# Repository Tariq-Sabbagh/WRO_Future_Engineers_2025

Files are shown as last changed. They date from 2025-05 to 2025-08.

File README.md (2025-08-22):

<center><h1>ITE  - Bloody Hilux WRO 2025 </center>

<p align="center">
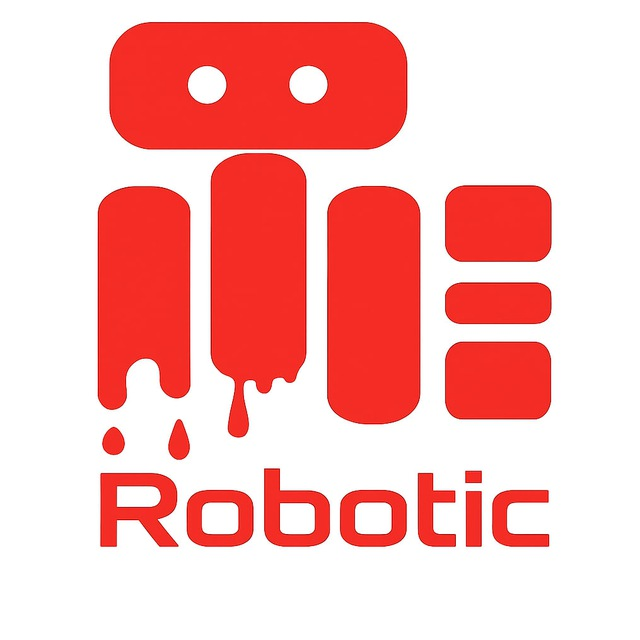
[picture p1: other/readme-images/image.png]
Banner
  
</p>





## Table of Contents

* [The Team](#team)
* [The Challenge](#challenge)
* [The Robot](#robot-image)
* [Performance Video](#video)
* [Mobility Management](#mobility-management)
  * [Powertrain](#powertrain-mechanical)
    * [Drive Motor](#motor-mechanical)
    * [Motor Driver](#motor-driver-mechanical)
  * [Steering](#steering-mechanical)
    * [Servo Motor](#servo-motor)
  * [Chassis](#chassis-mechanical)
* [Power and Sense Management](#power-and-sense-management)
  * [PCB Design](#pcb)
  * [Main Processor](#main-processor)
  * [Microcontroller](#microcontroller)
  * [Li-Po Battery](#li-ion-battery)
  * [Power Regulation](#power-regulation)
  * [Sensors](#sensors)
* [Code and Algorithms](#code-and-algorithms)
  * [Vision Processing and Obstacle Detection (Python)](#obstacle-management)
  * [Real-Time Control and State Machine (C++)](#real-time-control)
* [License](#copyright)

---

## The Team 

### [Team Member 1 Tariq Al-Sabbagh Al-Taji]

<p align="center">
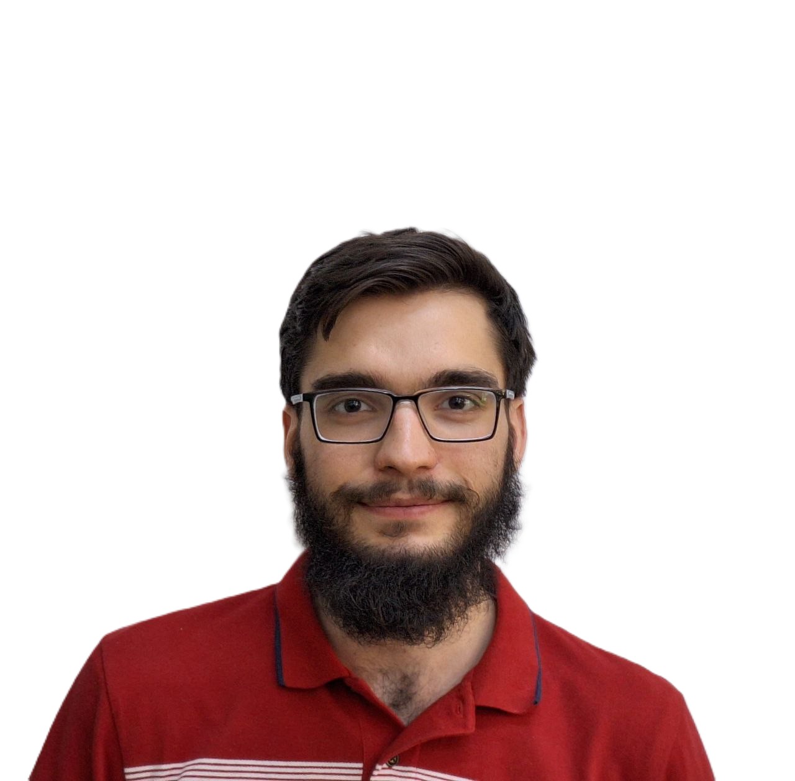
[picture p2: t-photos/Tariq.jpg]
Tariq sabbagh
  
</p>

<b>Role:</b> Programmer

<b>Age:</b> 21

<b>University:</b> Damascus University

<b>Description:</b>  A third-year Information Technology Engineering student at Damascus University. He is a backend developer and a volunteer at the Robotics Club.

---

### [Team Member 2 Tayseer Matar]

<p align="center">
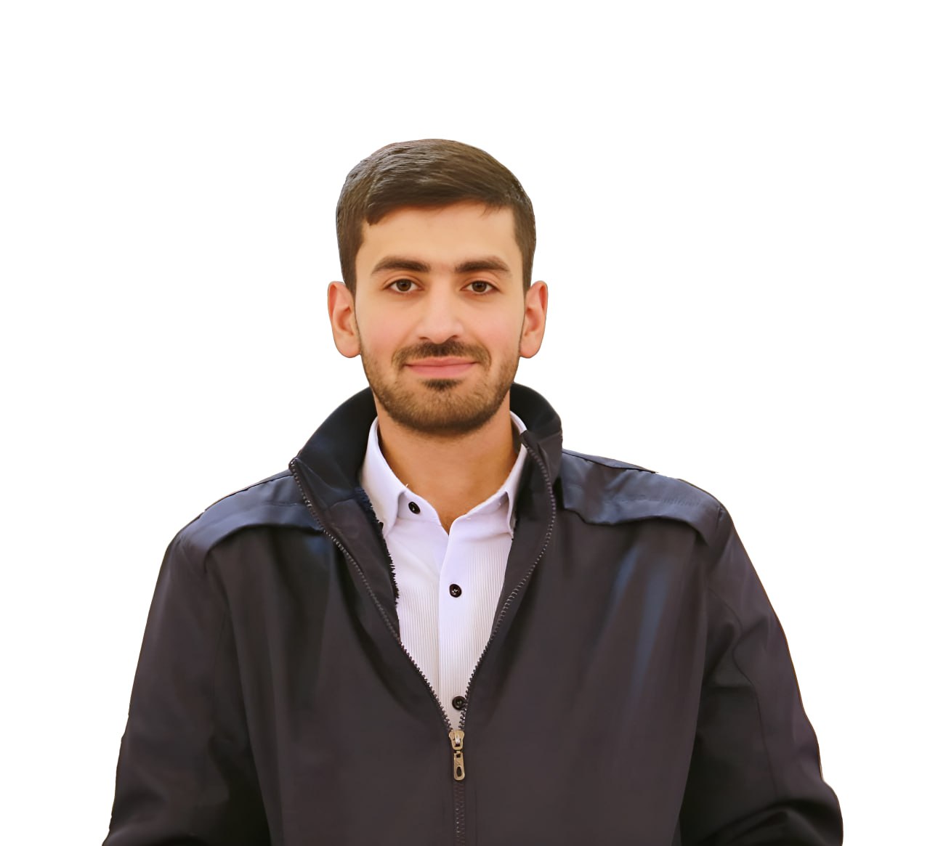
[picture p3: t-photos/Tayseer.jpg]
Tayseer matar
  
</p>

<b>Role:</b> Electrical

<b>Age:</b> 21

<b>University:</b> Damascus University

<b>Description:</b> A third-year Information Technology Engineering student at Damascus University. He is a frontend developer and a volunteer at the Robotics Club.

---

### [Team Member 3 Abdulrahman Qassouma]

<p align="center">
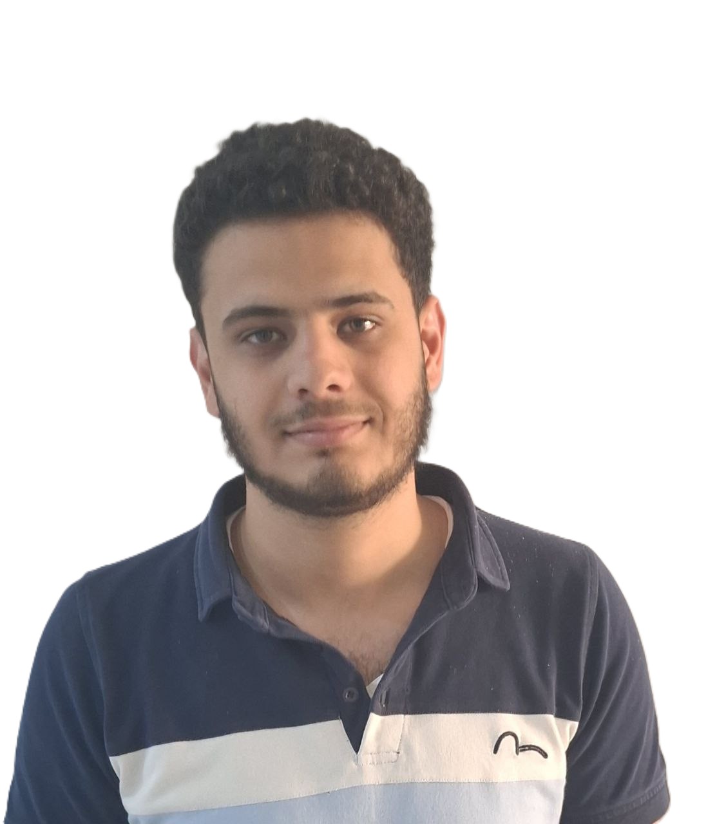
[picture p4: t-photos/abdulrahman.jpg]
Abdulrahman qassouma
  
</p>

<b>Role:</b> 3D design and the development of mechanical systems

<b>Age:</b> 21

<b>University:</b> Damascus University

<b>Description:</b>  A second-year Mechanical Design Engineering student at Damascus University. He specializes in 3D design and the development of mechanical systems.

---

### [Mohammed Mouaaz Sweid]

<p align="center">
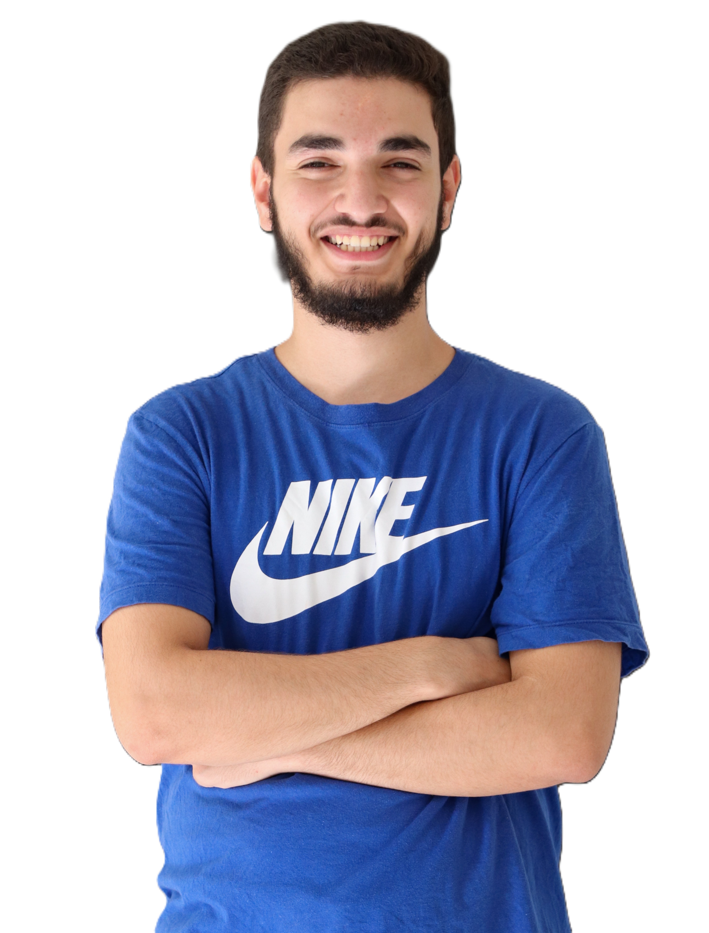
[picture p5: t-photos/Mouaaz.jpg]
Mohammed Moaz Sweid
  
</p>

<b>Role:</b> Coach

<b>Description:</b> A third-year Information Technology  Engineering student at Damascus University. He is a backend and DevOps developer and serves as a coach at the university's Robotics Club.

---

### Team Photo

<p align="center">
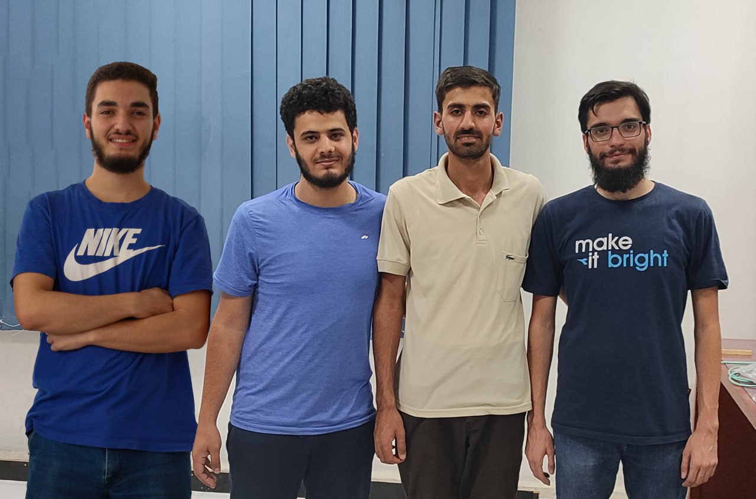
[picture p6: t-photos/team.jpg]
team Photo
  
</p>

## The Challenge 

The **[WRO 2025 Future Engineers - Self-Driving Cars](https://wro-association.org/)** challenge invites teams to design, build, and program a robotic vehicle capable of driving autonomously on a racetrack that changes dynamically for each round. The competition includes two main tasks: completing laps while navigating randomized obstacles and successfully performing a precise parallel parking maneuver.

---

## Photos of our robot Bloody Hilux 

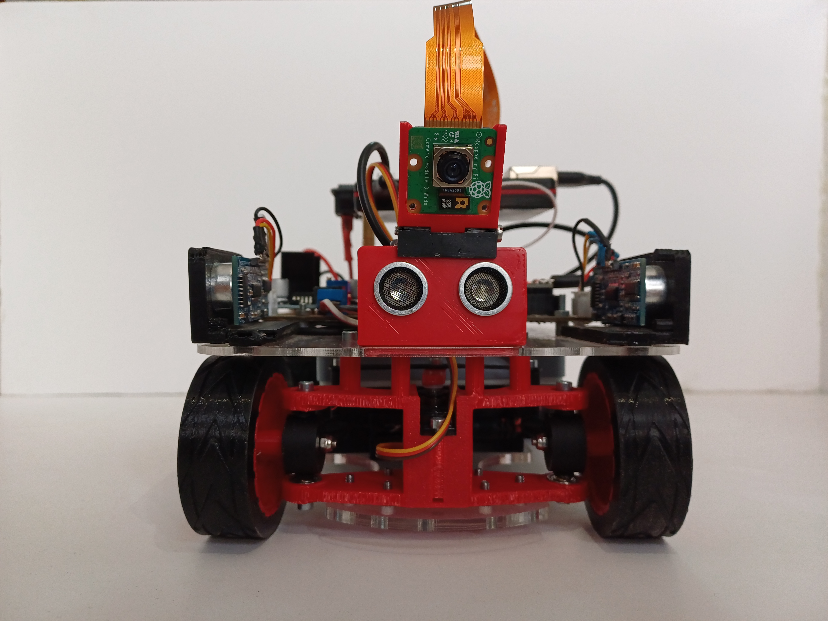
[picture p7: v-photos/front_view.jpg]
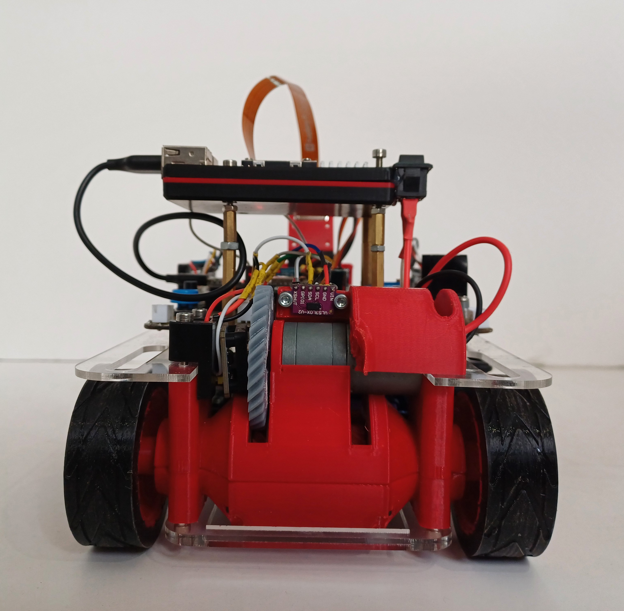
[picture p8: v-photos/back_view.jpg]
 |  | 

| *Front* | *Back* |

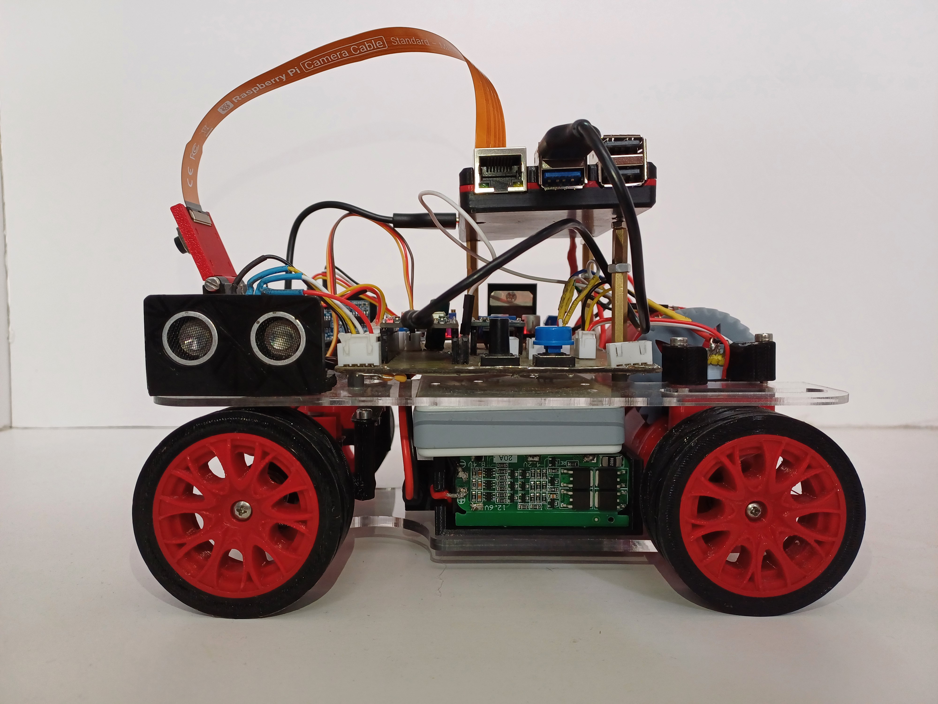
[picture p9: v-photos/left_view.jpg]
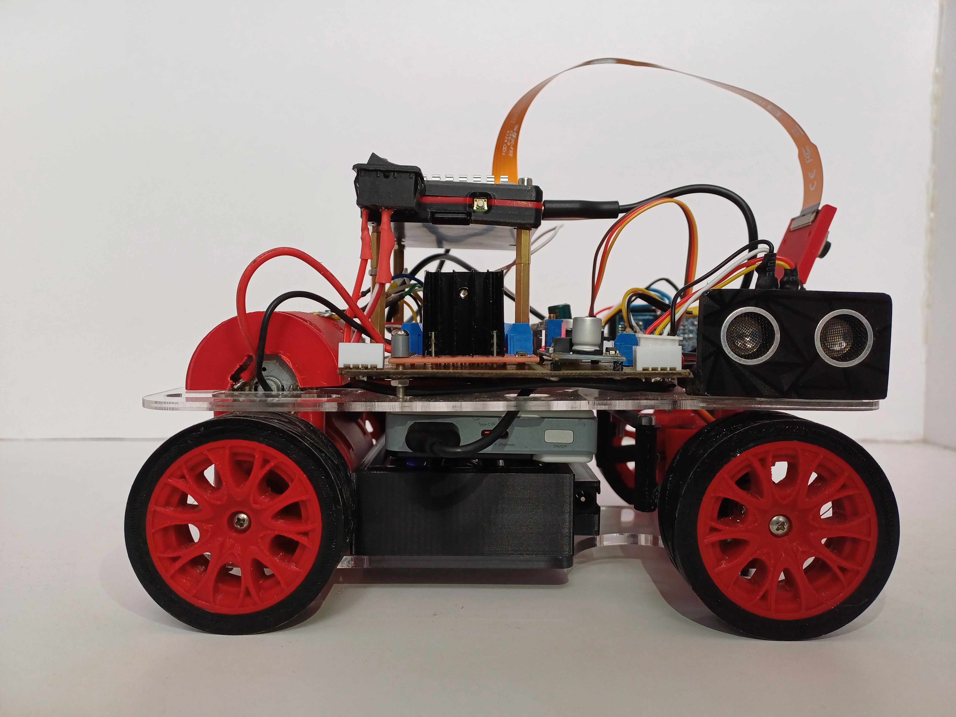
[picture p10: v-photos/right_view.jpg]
 |  | 

| *Left* | *Right* |

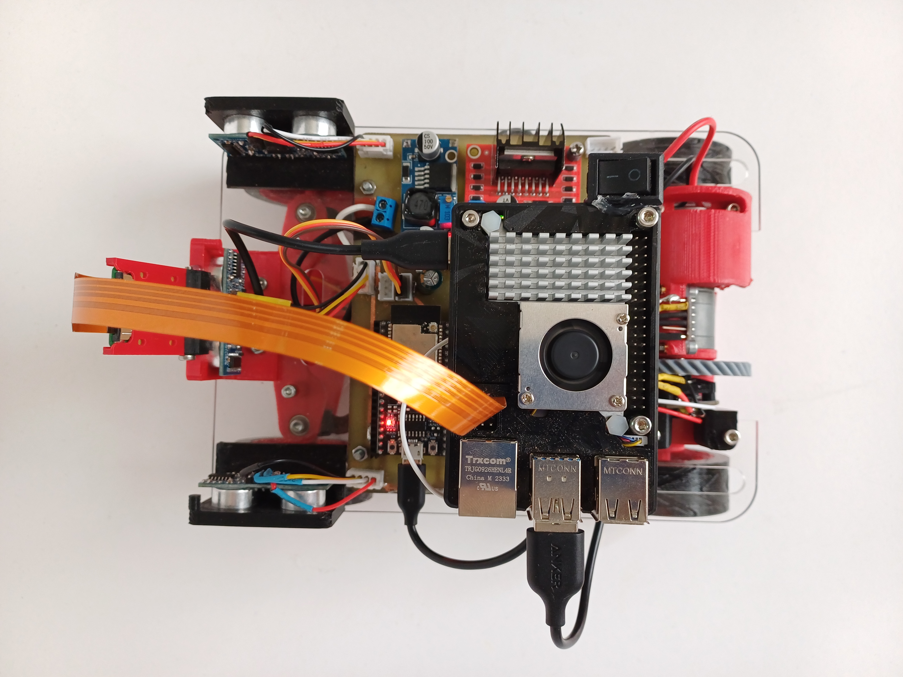
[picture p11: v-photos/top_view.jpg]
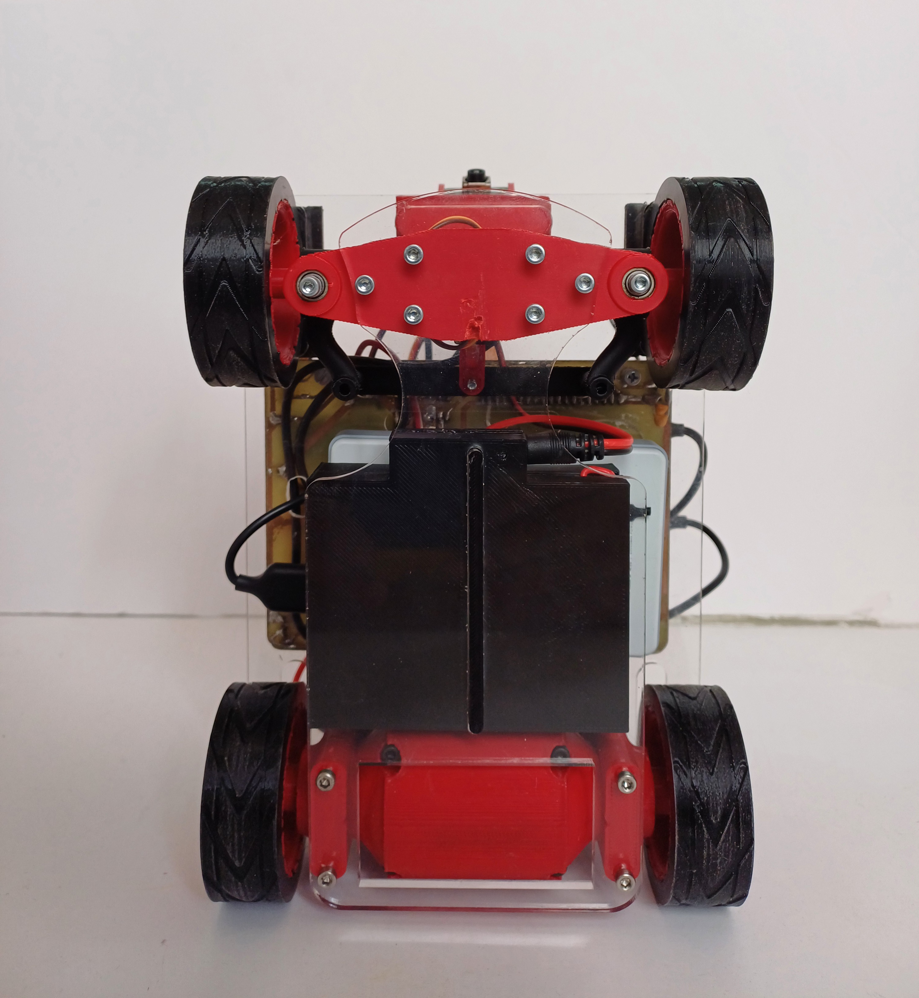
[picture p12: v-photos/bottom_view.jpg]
 |  | 

| *Top* | *Bottom* |

<br>

## Our video of the robot on [Youtube](https://youtu.be/ZicO00x3EqA?feature=shared) 

<a href="https://youtu.be/ZicO00x3EqA?feature=shared" target="_blank">
 <p align="center">
  WRO 2025 Robot Performance Video
 </p>
</a>

<br>

# [Mobility Management](https://github.com/Tariq-Sabbagh/WRO_Future_Engineers_2025/blob/main/models/README.md) 
Our robot's mechanical design is engineered for a precise balance of speed, stability, and cornering efficiency. The core components—powertrain, steering, and chassis—work together to achieve reliable and consistent performance on the track.

## Powertrain 

### Drive Motor 

<table>
  <tr>
    <td width="50%" style="text-align: left;">
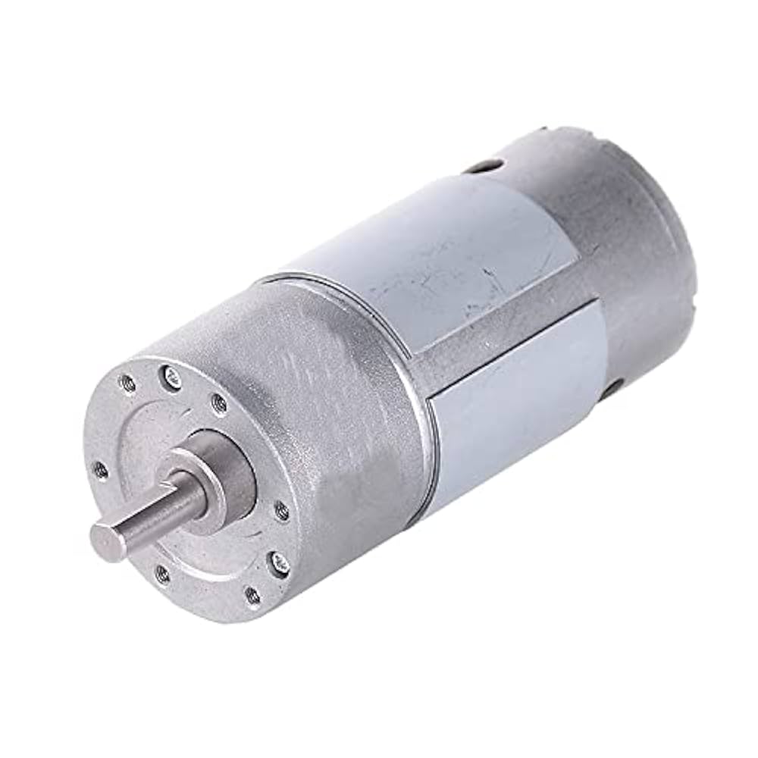
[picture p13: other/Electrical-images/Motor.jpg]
DC Motor
  
</td>
    <td width="50%" style="text-align: left; vertical-align: top;">
      <h3>Specifications:</h3>
      <li>Voltage: 12 V</li>
      <li>Speed: 281 RPM</li>
      <li>Torque: 5 kgf·cm (~0.49 N·m)</li>
    </td>
  </tr>
</table>

**Description:** This DC motor was selected because it provides the best trade-off between torque and speed. It ensures strong acceleration and a reliable top speed on straight tracks. The motor is paired with a 2.2:1 gear ratio to increase wheel speed, a suitable trade-off for the flat competition track.

### Motor Driver 
<table>
  <tr>
    <td width="50%" style="text-align: left;">
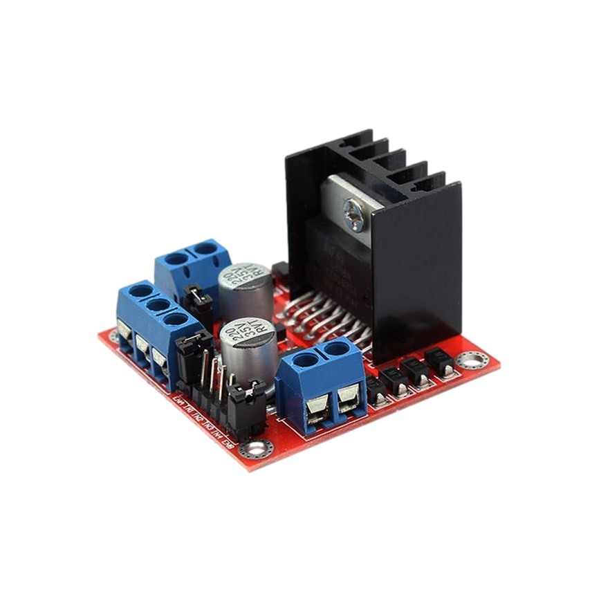
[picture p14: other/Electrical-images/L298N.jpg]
  
</td>
    <td width="50%" style="text-align: left; vertical-align: top;">
      <h3>Specifications:</h3>
      <li>Power supply voltage: 12V</li>
      <li>Output current: Up to 2A per channel</li>
      <li>Control: PWM for speed, Digital pins for direction</li>
    </td>
  </tr>
</table>

**Description:** We are using the L298N motor driver to safely interface the ESP32 with the high-current DC motor. It allows us to control both the speed (via PWM) and the direction of the motor. It is powered directly from the 12V battery pack.

## Steering 

**Description:** Our steering system is custom-designed based on Ackermann geometry. This ensures that the inner and outer wheels follow their correct turning radii (inner wheel at 65°, outer at 38°), which minimizes tire drag and makes cornering highly precise and stable. The mechanism is built with custom 3D-printed parts and durable linkages.

### Servo Motor 

<table>
  <tr>
    <td width="50%" style="text-align: left;">
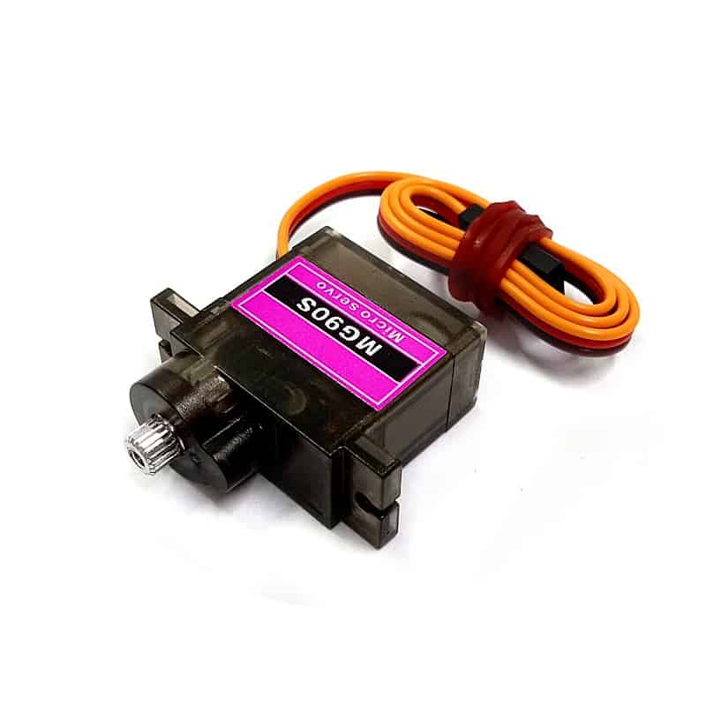
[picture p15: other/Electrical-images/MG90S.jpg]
  
</td>
    <td width="50%" style="text-align: left; vertical-align: top;">
      <h3>Specifications:</h3>
      <li>Weight: 9.3 g</li>
      <li>Rotation angle: 0 - 180</li>
    </td>
  </tr>
</table>

**Description:** A single servo motor actuates our Ackermann steering mechanism. It was chosen for its reliability and sufficient torque to handle the steering linkages under load.

## Chassis 

**Description:** The chassis is a hybrid construction using two plexiglass plates as the main structure, connected by custom 3D-printed support components. This design provides an excellent balance of durability and lightness, with a total weight of approximately 1.25 – 1.3 kg. All components are strategically placed to keep the center of gravity low, which is critical for maintaining stability at high speeds and during sharp turns.

Chassis

---

# # [Power and Sense Management](https://github.com/Tariq-Sabbagh/WRO_Future_Engineers_2025/blob/main/e-schemes/README.md) 
Our robot's electronic system is a two-part brain, with a Raspberry Pi 5 handling high-level vision processing and an ESP32 managing real-time hardware control. This distributed architecture ensures that complex calculations do not interfere with the precise, low-latency actions required for navigation.

### PCB Design 

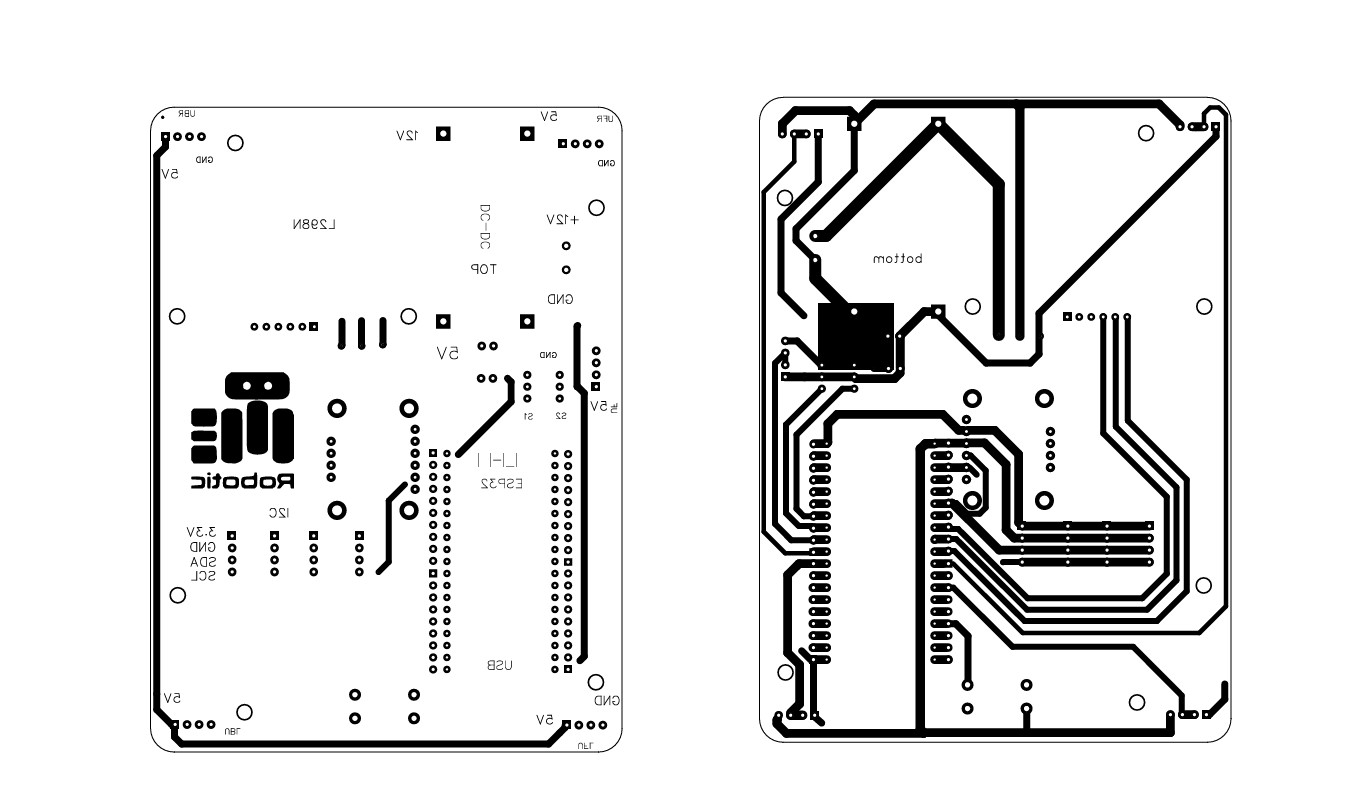
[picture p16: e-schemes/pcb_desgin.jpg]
PCB Design


**Description:** To ensure reliable connections and an organized layout, we integrated all our core electronic components onto a central PCB. This board serves as the main hub for power distribution, taking the 12V input from the battery pack and routing it through the power switch and LM2596 voltage regulator to supply all other components. Using a PCB instead of loose wires significantly improves the robot's durability by preventing accidental disconnections and makes troubleshooting much easier.

### Main Processor 
<table>
  <tr>
   <td width="50%" style="text-align: left;">
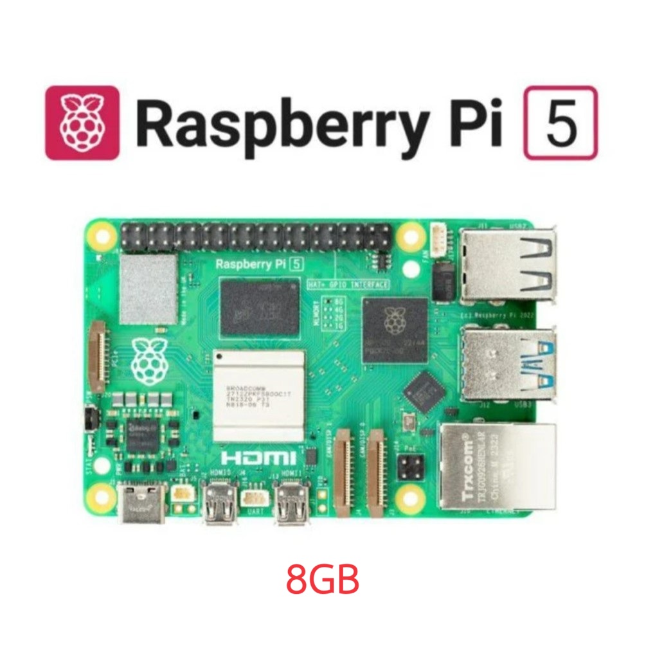
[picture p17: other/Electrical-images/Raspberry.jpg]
  
</td>
    <td width="50%" style="text-align: left; vertical-align: top;">
      <h3>Specifications:</h3>
      <li>Processor: Broadcom BCM2712 2.4GHz quad-core 64-bit Arm Cortex-A76 CPU</li>
      <li>RAM: 8 GB</li>
      <li>Power: 5V/5A DC via USB-C</li>
    </td>
  </tr>
</table>

**Description:** The Raspberry Pi 5 serves as the main brain for all high-level computations. It runs our Python-based computer vision algorithms using OpenCV to process the camera feed, detect obstacles, and identify turn indicators. It then sends high-level commands (e.g., "avoid obstacle at this angle") to the ESP32 via USB serial communication.

### Microcontroller
<table>
  <tr>
    <td width="50%" style="text-align: left;">
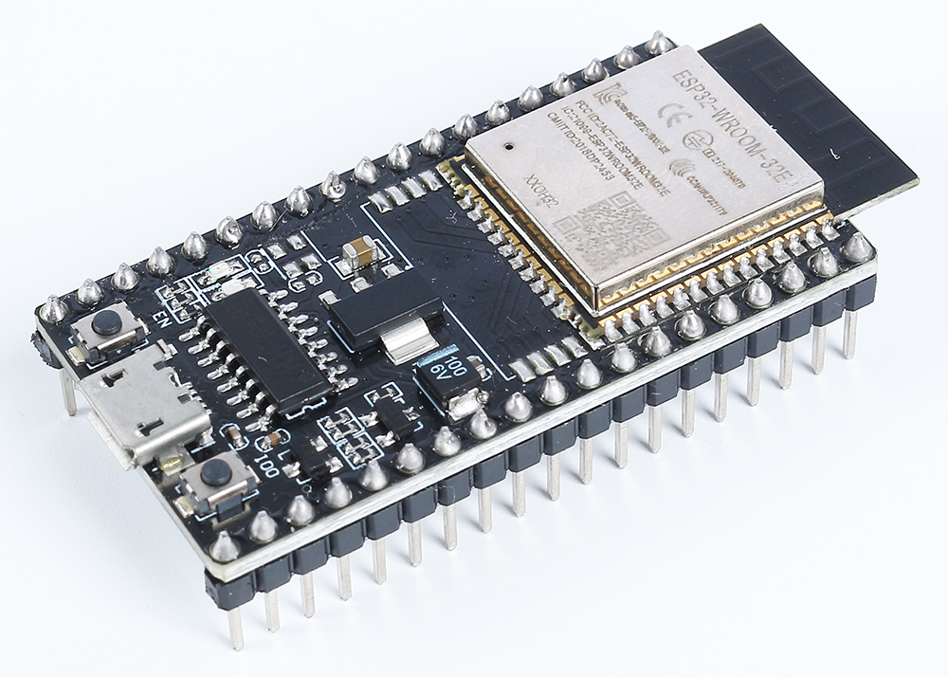
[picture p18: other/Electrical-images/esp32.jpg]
  
</td>
    <td width="50%" style="text-align: left; vertical-align: top;">
      <h3>Specifications:</h3>
      <li>Microcontroller: ESP32</li>
      <li>Frequency: 240 MHz (Dual Core)</li>
      <li>Flash memory: 4 MB</li>
    </td>
  </tr>
</table>

**Description:**We chose the ESP32 for its powerful dual-core processor and reliability in real-time operations. It acts as the hardware controller, executing the commands sent by the Raspberry Pi. Its responsibilities include generating precise PWM signals for the motor and servo, and gathering data from all the low-level sensors (IMU, Encoders, etc.) with minimal latency.

### Li-ion Battery 

<table>
  <tr>
   <td width="50%" style="text-align: left;">
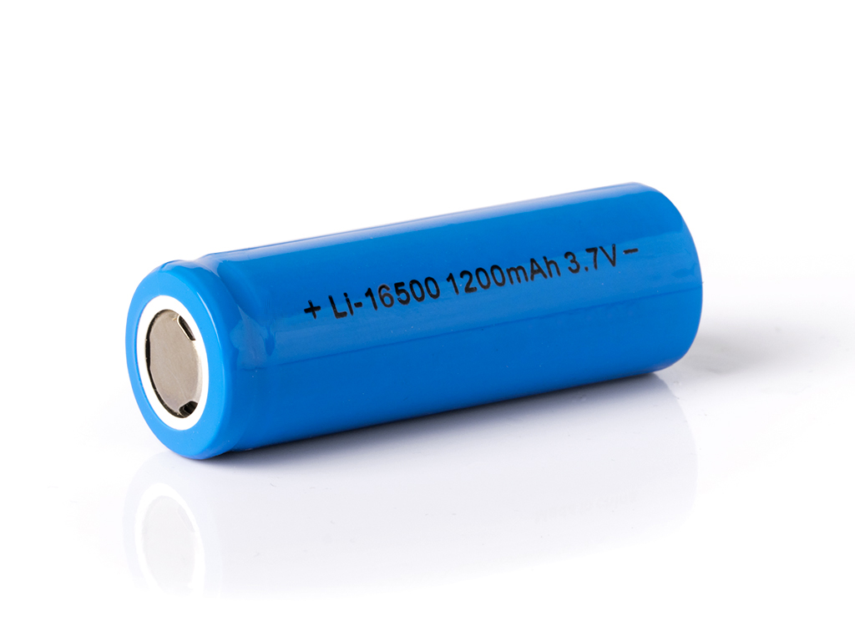
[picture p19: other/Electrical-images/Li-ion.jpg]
  
</td>
    <td width="50%" style="text-align: left; vertical-align: top;">
      <h3>Specifications:</h3>
      <li>Capacity: 5000 mA</li>
      <li>Voltage: 12V (3S Configuration)</li>
      <li>Protection: BMS 3S for overcharge/discharge protection</li>
    </td>
  </tr>
</table>

**Description:**  The main power for the motors and PCB comes from a 12V battery pack, constructed from three 18650 Li-ion cells in series. A BMS 3S board is integrated to ensure safe charging, prevent over-discharge, and provide a stable 12V output. This power is regulated by an LM2596 step-down converter for the electronics

### Power Regulation
<table>
  <tr>
    <td width="50%" style="text-align: left;">
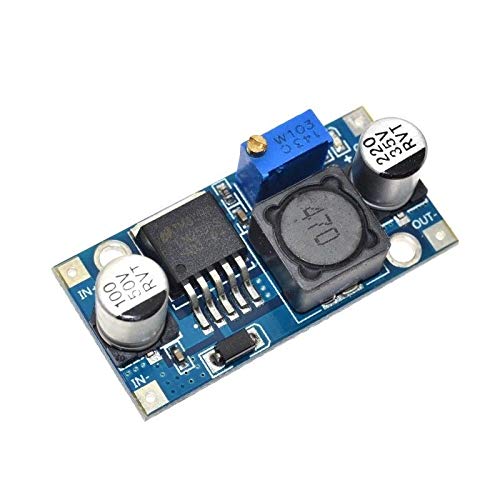
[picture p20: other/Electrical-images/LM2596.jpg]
  
</td>
    <td width="50%" style="text-align: left; vertical-align: top;">
      <h3>Specifications:</h3>
      <li>Input Voltage: 12V</li>
      <li>Output Voltage: 5V / 3.3V (Adjustable)</li>
      <li>Max Current: 3A</li>
    </td>
  </tr>
</table>

**Description:** An LM2596 step-down voltage regulator is used to convert the 12V from the main battery pack into a stable 5V or 3.3V supply for the microcontrollers and sensors. This is crucial for protecting the sensitive electronics from the high voltage of the battery.

### Sensors  

#### Camera
<table>
  <tr>
   <td width="50%" style="text-align: left;">
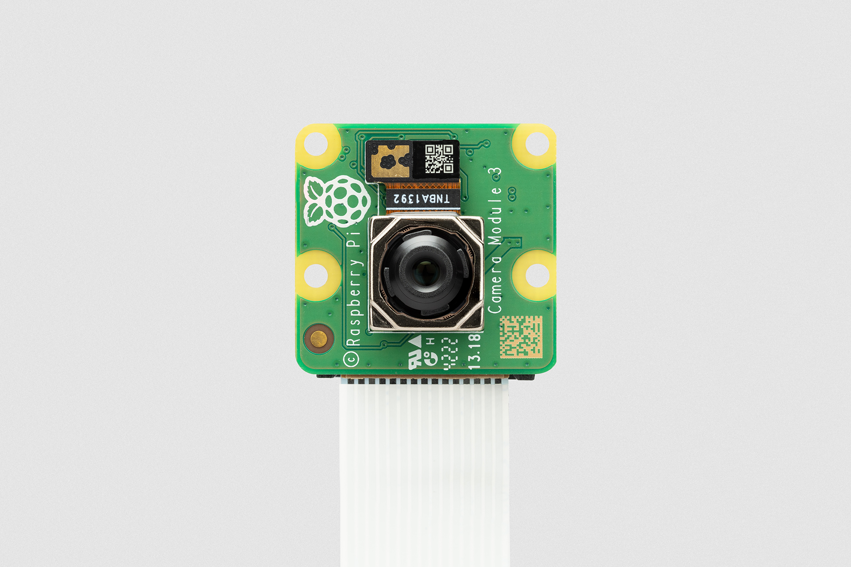
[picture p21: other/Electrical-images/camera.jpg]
  
</td>
    <td width="50%" style="text-align: left; vertical-align: top;">
      <h3>Specifications:</h3>
      <li>Resolution: 12 Megapixels (4056×3040)</li>
      <li>Frame rate: Up to 60 fps</li>
    </td>
  </tr>
</table>

**Description:**  The Raspberry Pi Camera V3 is our primary sensor for vision processing. Connected directly to the Raspberry Pi 5, it provides a high-resolution video stream that is analyzed in real-time to detect colored obstacles and track lines on the course.

#### IMU Sensor

<table>
  <tr>
    <td width="50%" style="text-align: left;">
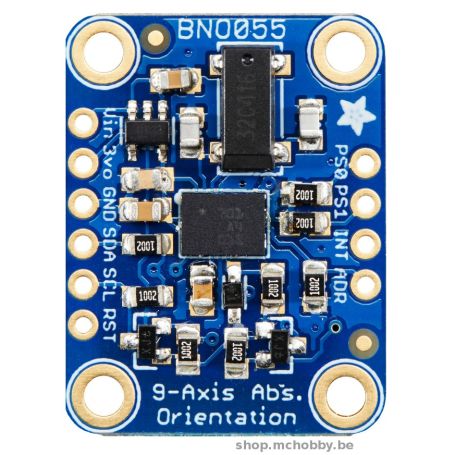
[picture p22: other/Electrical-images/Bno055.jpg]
  
</td>
    <td width="50%" style="text-align: left; vertical-align: top;">
      <h3>Specifications:</h3>
      <li>Gyroscope range: ±2000 dps</li>
      <li>Accelerometer range: ±4g</li>
      <li>Communication: I2C</li>
    </td>
  </tr>
</table>

**Description:** The BNO055 IMU is crucial for navigation and stability. It provides accurate orientation data (heading), which is fed into our PID steering controller. This allows the robot to drive in a perfectly straight line and execute turns with high precision.

#### Ultrasonic Sensors
<table>
  <tr>
  <td width="50%" style="text-align: left;">
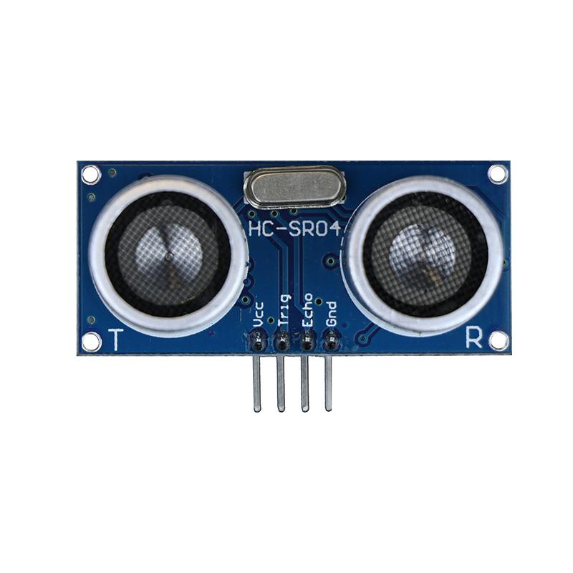
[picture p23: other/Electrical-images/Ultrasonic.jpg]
  
</td>
    <td width="50%" style="text-align: left; vertical-align: top;">
      <h3>Specifications:</h3>
      <li>Range: 2cm - 400cm</li>
      <li>Purpose: Wall and obstacle detection</li>
    </td>
  </tr>
</table>

**Description:** Three ultrasonic sensors (front, left, and right) are used for general distance measurement and obstacle avoidance. They provide reliable data for detecting walls during turns and serve as a secondary system to the camera for avoiding unexpected objects.

#### Time-of-Flight (ToF) Sensor

<table>
  <tr>
   <td width="50%" style="text-align: left;">
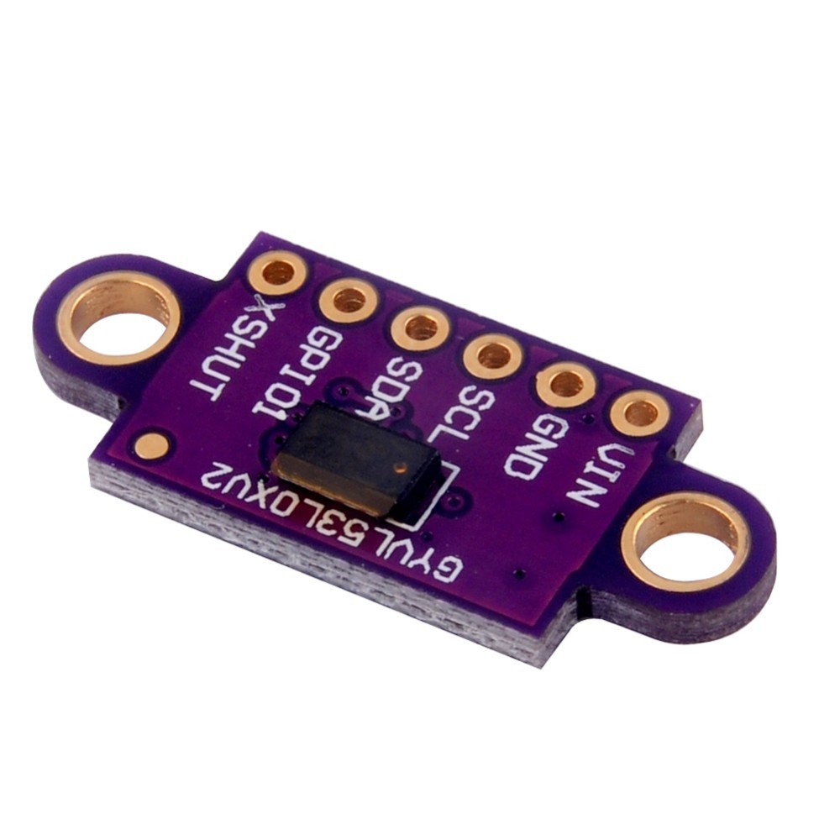
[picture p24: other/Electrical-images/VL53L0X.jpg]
  
</td>
    <td width="50%" style="text-align: left; vertical-align: top;">
      <h3>Specifications:</h3>
      <li>Range: Up to 2m</li>
      <li>Technology: Laser-based</li>
      <li>Communication: I2C</li>
    </td>
  </tr>
</table>

**Description:**  A VL53L0X ToF sensor is mounted on the rear of the robot. It uses a laser to measure distances with high speed and precision. Its primary role is to accurately position the robot against the back wall after a turn, ensuring a consistent starting point for each new section of the track.

#### Magnetic Encoder
<table>
  <tr>
   <td width="50%" style="text-align: left;">
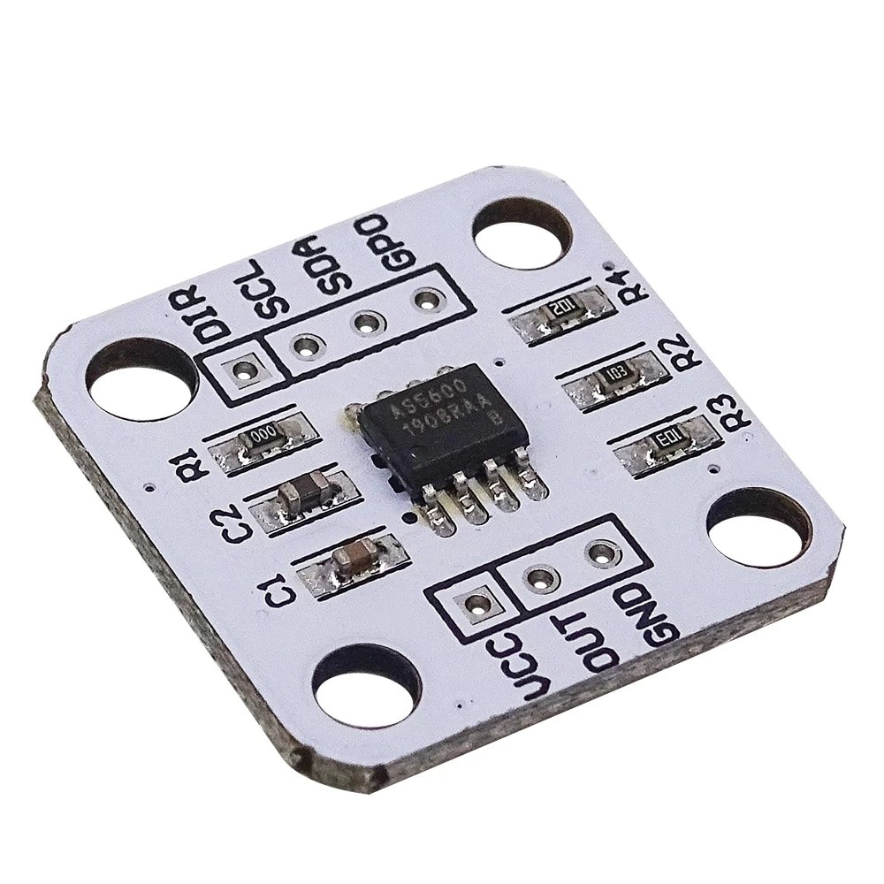
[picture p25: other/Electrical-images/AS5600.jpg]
  
</td>
    <td width="50%" style="text-align: left; vertical-align: top;">
      <h3>Specifications:</h3>
      <li>Resolution: 12-bit (4096 positions per revolution)</li>
      <li>Technology: Hall-effect</li>
      <li>Communication: I2C</li>
    </td>
  </tr>
</table>

**Description:** The AS5600 magnetic encoder is attached to the motor shaft to provide high-precision feedback on wheel rotation. This allows us to accurately track the distance traveled, which is essential for executing precise avoidance maneuvers and for odometry calculations.

# [ Code and Algorithms ](https://github.com/Tariq-Sabbagh/WRO_Future_Engineers_2025/blob/main/src/README.md)

Our robot's intelligence is built on a distributed software architecture. A Python script on the `Raspberry Pi 5` handles all the complex computer vision tasks, acting as the "eyes" of the robot. It communicates high-level commands to a C++ firmware running on the `ESP32`, which serves as the "nervous system," executing physical movements with real-time precision.

# Vision Processing and Obstacle Detection (Python) 

The core of our autonomous navigation is the vision script running on the Raspberry Pi. It processes the camera feed in real-time to identify obstacles and turn indicators.

* **Reliable Color Detection:** To detect objects under varying lighting conditions, we convert images from RGB to the LAB color space. This allows us to isolate specific colors accurately, regardless of shadows or bright spots on the track.

* **Focused Processing (ROI):** To improve performance and reduce false detections, we don't process the entire image. Instead, we define a specific Region of Interest (ROI) in the lower part of the frame where we expect to see the track, focusing our processing power only where it matters.

* **Maneuver Calculation:** When an obstacle is detected, the script calculates a precise avoidance maneuver. It estimates the distance to the obstacle based on its apparent height and the required steering angle based on its horizontal position. These two values are then sent as a single command to the ESP32.

```python
def process_obstacle(self, contour, frame_rgb, color_type):
    # Calculate distance from the obstacle's height
    distance = self.calculate_distance(h)
    # Calculate the angle and path to avoid it
    travel_dist, turn_angle = self.calculate_maneuver(...)

    # Send the command to the robot
    self.send_command('AVOID', travel_dist, turn_angle)
```

# Real-Time Control and State Machine (C++) 
The ESP32 firmware is designed for robust, real-time control. It receives commands from the Raspberry Pi and translates them into precise hardware actions using a clean and predictable structure.

* **State Machine:** The core of the firmware is a state machine. The robot operates in distinct states such as FORWARD, AVOIDING, TURN, and RESET. This approach allows us to manage complex sequences of actions in an organized way, making the robot's behavior reliable and easy to debug.
```cpp
void ObstacleAvoider::loop()
{
    // ... update sensors and check for commands ...

    switch (_currentState)
    {
    case AVOIDING: _avoidObstacle(); break;
    case FORWARD:  _goForward();     break;
    case TURN:     _turn();          break;
    case RESET:    _resetCar();      break;
    }
}
```

* **PID Control for Precision:** To drive perfectly straight and execute smooth turns, we use a PID controller. It continuously takes the current heading from the `BNO055 IMU` and compares it to the target heading, calculating the exact steering correction needed. This feedback loop is the key to our robot s stability and accuracy.

* **Code Structure and Helper Classes:** To keep the main logic clean, our C++ code is heavily object-oriented. We developed a suite of helper classes, where each class is responsible for managing a single piece of hardware (e.g., `MotorController`, `IMU`, `Encoder`, `PIDController`). This abstraction allows us to easily manage complex hardware interactions without cluttering the main state machine.

## Copyright 

```
MIT License

Copyright (c) 2025 Bloody Hilux

Permission is hereby granted, free of charge, to any person obtaining a copy
of this software and associated documentation files (the "Software"), to deal
in the Software without restriction, including without limitation the rights
to use, copy, modify, merge, publish, distribute, sublicense, and/or sell
copies of the Software, and to permit persons to whom the Software is
furnished to do so, subject to the following conditions:

The above copyright notice and this permission notice shall be included in all
copies or substantial portions of the Software.

THE SOFTWARE IS PROVIDED "AS IS", WITHOUT WARRANTY OF ANY KIND, EXPRESS OR
IMPLIED, INCLUDING BUT NOT LIMITED TO THE WARRANTIES OF MERCHANTABILITY,
FITNESS FOR A PARTICULAR PURPOSE AND NONINFRINGEMENT. IN NO EVENT SHALL THE
AUTHORS OR COPYRIGHT HOLDERS BE LIABLE FOR ANY CLAIM, DAMAGES OR OTHER
LIABILITY, WHETHER IN AN ACTION OF CONTRACT, TORT OR OTHERWISE, ARISING FROM,
OUT OF OR IN CONNECTION WITH THE SOFTWARE OR THE USE OR OTHER DEALINGS IN THE
SOFTWARE.

```

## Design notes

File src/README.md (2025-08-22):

# Code Logic and Strategy

## Open Challenge

### Core Logic: The `Car` Class

To keep our code organized and easy to manage, we built our entire driving logic inside a single C++ class called `Car`. This class acts as the "brain" of our robot. It brings together all the different hardware components—motors, steering, sensors—and uses a clear algorithm to navigate the challenge track.

Here is the basic structure of our `Car` class:
```cpp
#include "PIDController.h"
#include "MotorController.h"
#include "Steering.h"
#include "DistanceSensors.h"
#include "IMU.h"
#include "Button.h"

class Car {
private:
    // All our hardware objects
    MotorController _motors;
    Steering _steering;
    DistanceSensors _distSensors;
    IMU _imu;
    Button _button;
    PIDController _pid;

    // Variables to track our state on the track
    float _offsetGyro;
    int _turnCounter;
    // ... and other state variables

    // The core actions the car can take
    void _checkForTurns();
    void _moveStraight();
    void _turnRight();
    void _turnLeft();
    void _stopAndHalt();

public:
    // Public functions to run the car
    Car();
    void setup();
    void loop();
};
```
Constructor: Car()
This is where the Car object is first created. Its main job is to initialize all the hardware component objects (like _motors, _steering, etc.) with their correct pin numbers. It also resets all our navigation variables to their starting values, ensuring a clean start for every run.
```cpp
Car::Car() :
    _motors(MOTOR_DIR1_PIN, MOTOR_DIR2_PIN, MOTOR_SPEED_PIN),
    _steering(SERVO_PIN),
    _distSensors(ULTRASONIC_PIN_FRONT, ULTRASONIC_PIN_LEFT, ULTRASONIC_PIN_RIGHT),
    _imu(),
    _button(BUTTON_PIN),
    _pid()
{
    // Reset state variables
    _offsetGyro = 0.0f;
    _turnCounter = 0;
    direction = "straight";
    // ... etc.
}
```
Setup Phase: setup()
The setup() function gets all the hardware ready to go. It configures our PID controller for smooth steering and initializes the IMU sensor. A key feature here is that the code waits for a button press. This allows us to place the robot on the track before it starts moving. Once the button is pressed, it calibrates the gyro by taking an initial reading to know its starting direction.
```cpp
void Car::setup() {
    // Setup all hardware components
    _motors.setup();
    _steering.setup();
    _button.setup();
    
    // Configure PID controller
    _pid.setup(STEERING_KP, 0, 0);
    _pid.setOutputLimits(-90,90);
    
    // Initialize IMU, and stop if it fails
    if (!_imu.setup()) {
        _stopAndHalt();
    }

    // Wait for the start signal
    _button.waitForPress();
    
    // Calibrate gyro to the starting direction
    _imu.update();
    _offsetGyro = _imu.getHeading();
}
```
Main Loop: loop()
This is the heart of our program that runs over and over. The logic is very simple and clear:

Update Sensors: Always get the latest data from the IMU first.

Check for Turns: See if the robot has reached an intersection where it needs to turn.

Drive Straight: Use the PID controller to maintain a perfectly straight line.

Check Finish Condition: After 12 turns, the robot knows the course is complete and stops.

```cpp
void Car::loop() {
    _imu.update(); // 1. Update Sensors
    
    _checkForTurns();   // 2. Check for Turns
    _moveStraight();    // 3. Drive Straight

    // 4. Check if we're done
    if (_turnCounter >= 12) {
        // ... stop the car
        _stopAndHalt();
    }
}
```

Core Functions Explained
_moveStraight()
This function is responsible for keeping the car on course. It constantly compares the car current heading (from the IMU gyro) to its target direction. The difference between these is the "error." This error is fed into a PID controller, which calculates the precise steering correction needed to get back on track. This allows the robot to drive very straight.

```cpp
void Car::_moveStraight() {
    // Calculate heading error relative to our starting direction
    float currentHeading = _imu.getHeading() - _offsetGyro;

    // Normalize the heading to a range of -180 to 180
    if (currentHeading > 180) currentHeading -= 360;
    else if (currentHeading < -180) currentHeading += 360;

    // Use the PID controller to calculate the steering correction
    float steeringCorrection = _pid.compute(0, currentHeading);

    // Apply the correction to the servo and move forward
    _steering.setAngle(-steeringCorrection);
    _motors.forward(FORWARD_SPEED);

}
```

_checkForTurns()
This function decides when and where to turn. Using data from our ultrasonic sensors, it detects when it has reached an open intersection. The logic follows the required pattern for the track. It also includes a "cooldown" to prevent it from making multiple turns right after each other.
```cpp
void Car::_checkForTurns() {
    // Wait for cooldown period to pass
    if (millis() - _previousTurnMillis < TURN_COOLDOWN_MS) {
        return;
    }

    // Only consider turning if we are driving mostly straight
    if (abs(error) < 15) {
        // Logic for deciding whether to turn left or right based on the lap number
        if (_turnCounter < 1) {
            _turnLeft();
        } 
        else if (direction == "right") {
            _turnRight();
        } 
        else if (direction == "left") {
            _turnLeft();
        }
    }
}
```

## Obstacle Challenge

### Obstacle Challenge: Vision Processing (Python):

For the obstacle challenge, our strategy relies on a Python script using the OpenCV library for all vision processing. The script analyzes the camera feed to detect obstacles and turn indicators, then sends commands to the ESP32 microcontroller. The logic is built around a state machine to manage different situations like driving forward, avoiding an obstacle, or turning.

These are the main states our robot can be in:
```cpp
enum State {
    FORWARD,    // Driving straight ahead
    AVOIDING,   // Actively maneuvering around an obstacle
    IDLE,       // Waiting for a command
    BACKWARD,   // Reversing (part of a maneuver)
    TURN,       // Making a 90-degree turn
    RESET,      // Resetting position after a maneuver
    GARAGE      // Parking maneuver
};
```

#### Color Detection using LAB Color Space
To reliably detect colored objects under different lighting conditions, we convert the camera image from the standard RGB format to the LAB color space. The 'L' channel represents lightness, while 'A' and 'B' represent color spectrums. This separation makes it much easier to identify a specific color regardless of shadows or bright lights.

We create a "mask" for each color we're looking for (red, green, blue, orange). This mask is a black and white image where white pixels represent the color we want to find.
```python
def detect_color(self, lab_frame, color_name):
    """Detect specific color in LAB space"""
    profile = self.COLOR_PROFILES[color_name]
    # Create a mask using the lower and upper LAB values for the color
    mask = cv2.inRange(lab_frame, profile['lower'], profile['upper'])
    # Clean up the mask to remove small noise
    kernel = np.ones((5, 5), np.uint8)
    mask = cv2.morphologyEx(mask, cv2.MORPH_CLOSE, kernel)
    mask = cv2.morphologyEx(mask, cv2.MORPH_OPEN, kernel)
    return mask
```
#### Main Vision Loop: process_frame()
This is the main function that runs for every frame from the camera. Its job is to find obstacles and turns.

Region of Interest (ROI): To improve performance and avoid detecting irrelevant objects in the background, we don't process the entire camera image. Instead, we define a specific rectangular area (an ROI) in the lower part of the frame where we expect to see the track and obstacles. All processing happens only inside this box.

Find Contours: Within the ROI, the code looks for continuous shapes (contours) of our target colors.

Process Obstacles/Turns: Once a colored shape is found, it's passed to another function to decide what to do.
```python
def process_frame(self , mode='rgb'):
    """Process a single frame"""
    frame_rgb = self.capture_frame()
    
    # 1. Define the Region of Interest (ROI)
    obstacle_roi_rgb = self.crop_frame(frame_rgb, 0.1, 0.07, 0.8, 0.7)

    # 2. Find all colored shapes (contours) in the ROI
    contours = self.detect_obstacles(obstacle_roi_rgb)
    dominant_color = self.find_dominant_obstacle(contours)
    
    # 3. Process the most important obstacle found
    if dominant_color:
        self.process_obstacle(
            contours[dominant_color],
            obstacle_roi_rgb,
            dominant_color
        )

    # Also, constantly check for turn indicators on the floor
    self.handle_turn_detection(frame_rgb)

    return frame_rgb
```

#### Handling Obstacles vs. Turns
The system handles obstacles (red/green blocks) differently from turn indicators (blue/orange floor markings).

Obstacle Avoidance (process_obstacle)
When a red or green obstacle is detected, this function calculates a maneuver.

It estimates the distance to the obstacle based on its apparent height in the image.

It calculates the angle needed to steer around it based on its horizontal position in the frame.

Finally, it sends an AVOID command to the ESP32 with the distance to travel and the angle to turn.
```python
def process_obstacle(self, contour, frame_rgb, color_type):
    # ...
    x, y, w, h = cv2.boundingRect(contour)
    # 1. Calculate distance from the obstacle's height
    distance = self.calculate_distance(h)
    # 2. Calculate the angle and path to avoid it
    travel_dist, turn_angle = self.calculate_maneuver(
        frame_rgb.shape, (x, y, w, h), distance, profile['offset_adjust']
    )
    # 3. Send the command to the robot
    if (self.mode is not OperationMode.CAMERA_ONLY) and travel_dist <= 70:
        self.send_command('AVOID', travel_dist, turn_angle)
```

#### Turn Detection (detect_turn)
For turns, we don't need to find a specific shape. We just need to know if there's a patch of blue or orange on the floor.

This function looks at a specific ROI on the floor.

It calculates the percentage of blue or orange pixels within that ROI.

If the percentage crosses a certain threshold (e.g., >10%), it confirms a turn and sends a TURN command to the ESP32 with the correct angle (-90 for left, 90 for right).
```python
def detect_turn(self, frame_rgb):
    # ...
    roi = self.crop_frame(frame_rgb, 0.375, 0.7, 0.25, 0.2)
    # ...
    for color in turn_map:
        mask = self.detect_color(frame_lab, color)
        # 2. Calculate the ratio of colored pixels
        pixel_ratio = np.sum(mask > 0) / mask.size
    
        # 3. If enough color is present, detect the turn
        if pixel_ratio > 0.1:
            turn_detected = turn_map[color]
            return turn_detected
    return None
```

### Obstacle Challenge: Microcontroller Logic (C++)
The ESP32 microcontroller receives the high-level commands from the Python script (like `AVOID` or `TURN`) and translates them into precise physical actions using its `ObstacleAvoider` class. It manages the motors and sensors to execute these maneuvers accurately.

#### Setup Phase: `setup()`
This function initializes all the hardware connected to the ESP32. It starts the motors, servo, sensors (IMU, TOF), and the PID controller. It also waits for a button press to begin the challenge, ensuring the robot is correctly positioned first.
```cpp
void ObstacleAvoider::setup()
{
    // Initialize communication and all hardware components
    Wire.begin();
    _motors.setup();
    _servo.setup();
    _button.setup();
    _encoder.begin();
    // Loop until the IMU is successfully initialized
    while (!_imu.setup())
    {
        Serial.println("FATAL: IMU failed to initialize.");
    }
    // Halt if the rear Time-of-Flight sensor fails
    if (!_backSensor.begin())
    {
        Serial.println("TOF Sensor failed to init!");
        while (1);
    }
    // Wait for the start button to be pressed
    _button.waitForPress();

    // Configure the PID controller for steering
    _pid.setup(3.5, 0, 0);
    _pid.setOutputLimits(-90, 90);

    // Initial maneuver to exit the garage
    _garageDoOut();
   
    // Clear any leftover data in the serial buffer
    _comm.clearSerialBuffer();
    Serial.println("Obstacle Avoider Initialized. Waiting for commands...");
}
```
#### Main Loop and State Machine: `loop()`
The main loop constantly updates sensor readings and checks for new commands from the Python script. It uses a `switch` statement to execute the code corresponding to the robot's current state (`FORWARD`, `AVOIDING`, `TURN`, etc.). This state-based approach makes the logic clean and predictable.
```cpp
void ObstacleAvoider::loop()
{
    // Always update sensor data and check for new commands
    _encoder.update();
    _imu.update();
    _comm.update();
    _backSensor.update();

    // If a turn command is received, switch to the TURN state
    if (_comm.getTurn() != 0.f and _currentState != GARAGE)
    {
        _currentState = TURN;
    }

    // Execute the function for the current state
    switch (_currentState)
    {
    case AVOIDING:
        _avoidObstacle();
        break;
    case FORWARD:
        _goForward();
        break;
    case TURN:
        _turn();
        break;
    case RESET:
        _resetCar();
        break;
    case GARAGE:
        _garageDoIn();
        break;
    // ... other states
    }
    // A function to prevent crashing into walls
    _get_away_walls();
    // Apply the final calculated steering angle
    _servo.setAngle(_steeringAngle);
}
```

#### State Explanations
`FORWARD` State:
This is the default state. The robot drives forward while using the PID controller to keep a straight line based on the IMU heading. It continuously listens for an `AVOID` command from the Python script. If a command is received, it switches to the `AVOIDING` state.
```cpp
void ObstacleAvoider::_goForward()
{
    // Check if a new maneuver command has arrived from the vision script
    if (_comm.getManeuverValues(distance, angle) and abs(_pid.geterror()) < 15)
    {
        // If so, reset sensors and switch to AVOIDING state
        _encoder.reset();
        _imu.reset();
        _currentState = AVOIDING;
    }
    else
    {
        // Otherwise, keep driving straight using PID control
        float correction = _pid.compute(_forwardTarget, _imu.getHeadingRotating());
        _steeringAngle = -correction;
        _motors.forward(FORWARD_SPEED);
    }
}
```
`AVOIDING` State:
In this state, the robot executes the avoidance maneuver calculated by the Python script. It steers to the specified `angle` and drives forward for the specified distance (the hypotenuse of the triangle). Once the `distance` is covered, it switches back to the   `FORWARD` state.
```cpp
void ObstacleAvoider::_avoidObstacle()
{
    float currentDistance = _encoder.getDistanceCm();

    // While we haven't traveled the required distance
    if (abs(currentDistance) <= distance)
    {
        // Use the PID controller to steer to the target angle
        float correction = _pid.compute(angle, _imu.getHeading());
        _steeringAngle = -correction;
        _motors.forward(FORWARD_SPEED);
    }
    else
    {
        // Once the maneuver is done, reset values and return to FORWARD state
        _comm.resetManeuverValues();
        _currentState = FORWARD;
    }
}
```
`TURN` State:
When a turn indicator is detected, the robot enters this state. It drives forward until it is close to the wall, then updates its target heading by +/- 90 degrees. After setting the new direction, it switches to the `RESET` state to physically align itself.
```cpp
void ObstacleAvoider::_turn()
{
    // Drive forward until the front wall is close
    if (_ultra.getFrontCm() <= 25 and _pid.geterror() < abs(20))
    {
        // Update the target heading for the new direction
        if(turn_right)
        {
            _forwardTarget += 90;
        }
        else 
        {
            _forwardTarget -= 90;
        }
        _comm.resetTurn();
        // After 11 turns, it's time to park
        if(count_turn >= 11)
        {
            _currentState = GARAGE;
        }
        else {
            // Otherwise, go to the RESET state to realign
            _currentState = RESET;
        }
    }
}
```
`RESET` State:
After a turn, the robot needs to be perfectly positioned for the next straight section. This function reverses the car until the rear Time-of-Flight sensor detects the back wall at a specific distance. This ensures the car starts each section from the same known position, making obstacle calculations more accurate. It then switches back to `FORWARD`.
```cpp
void ObstacleAvoider::_resetCar()
{
    // Use PID to maintain the new target heading while reversing
    float correction = _pid.compute(_forwardTarget, _imu.getHeadingRotating());
    _steeringAngle = correction;
    
    // Drive backwards
    _motors.move(BACKWARD_SPEED);
    
    int distanceTOF = _backSensor.getDistance();
    // Stop reversing when the back wall is at the target distance and the car is straight
    if (distanceTOF <= 350 and abs(_pid.geterror()) < 15)
    {
        count_turn++;
        _motors.move(FORWARD_SPEED); // Give a small forward push
        _currentState = FORWARD; // Return to the default state
    }
}
```
`GARAGE` State:
This is the final state, triggered after 12 turns are completed. It contains the specific sequence of movements required to perform the parallel parking maneuver into the garage area to finish the run.
```cpp
void ObstacleAvoider::_garageDoIn()
{
    // This function contains a hardcoded sequence of turns and movements
    // to navigate the car into the final parking spot.
    // It uses the IMU for turns and sensors for positioning against walls.
    int motorSpeedGarage = 190;
 
    // ... complex sequence of turns, forward, and backward movements ...
    
    // Once parked, stop all motors and end the program.
    _motors.stop();
    while (true);
}
```

## Helper Classes and Abstractions
To keep our main code clean and readable, we created several "helper" classes. Each class is responsible for managing one specific piece of hardware or one specific task. This approach, known as abstraction, makes the code easier to debug and reuse.

`Button` Class
A simple class to manage the physical start button. It handles basic operations like checking if the button is pressed and waiting for a press to start the robot's routine.
```cpp
#ifndef BUTTON_H
#define BUTTON_H

#include <Arduino.h>

class Button {
public:
    Button(int pin); // Constructor: sets the button's pin number
    void setup(); // Initializes the pin as an input
    bool isActive();   // Returns true if the button is currently pressed
    bool isInactive(); // Returns true if the button is not pressed
    void waitForPress(const char *message = ""); // Pauses the program until the button is pressed

private:
    int _pin; // Stores the GPIO pin number for the button
};

#endif // BUTTON_H
```
`DistanceSensors` Class
This class manages the three ultrasonic sensors (front, left, and right). It uses the NewPing library for measurements and includes a Kalman filter to smooth out the readings and provide more stable distance data.

```cpp
#ifndef DISTANCE_SENSORS_H
#define DISTANCE_SENSORS_H

#include <Arduino.h>
#include <NewPing.h>

#define ULTRASONIC_MAX_DISTANCE_CM 400
#define MEDIAN_SAMPLES 5

class DistanceSensors {
public:
    // Constructor: sets the pins for the three ultrasonic sensors
    DistanceSensors(int front_pin, int left_pin, int right_pin);

    float getFrontCm(); // Returns the filtered distance from the front sensor in cm
    float getLeftCm();  // Returns the filtered distance from the left sensor in cm
    float getRightCm(); // Returns the filtered distance from the right sensor in cm

private:
    // NewPing objects for each sensor
    NewPing _sonar_front;
    NewPing _sonar_left;
    NewPing _sonar_right;

    // Variables for the Kalman filter to reduce sensor noise
    float _kalman_front, _kalman_left, _kalman_right;
    float _error_front, _error_left, _error_right;
    const float _kalmanQ, _kalmanR;

    float median(NewPing& sensor, int samples); // Takes a median of readings to reject outliers
    float kalman(float measurement, float& estimate, float& error); // Applies a Kalman filter for smoother data
};

#endif
```

`Encoder` Class
This class interfaces with the AS5600 magnetic encoder. Its main purpose is to track the rotation of the wheels and calculate the total distance the robot has traveled in centimeters.
```cpp
#ifndef ENCODER_H
#define ENCODER_H

#include <Arduino.h>
#include <AS5600.h>
#include <Wire.h>
#include "config.h"

class Encoder {
public:
    Encoder(); // Constructor
    bool begin(); // Initializes the AS5600 sensor
    void update(); // Should be called repeatedly to read the sensor and calculate distance
    void reset(); // Resets the total traveled distance to zero
    float getDistanceCm() const; // Returns the total distance traveled since the last reset

private:
    AS5600 _as5600; // The sensor library object
    int _lastAngle; // Stores the previous angle reading to calculate rotation
    float _totalAngle; // Accumulates the total angle of rotation
    float _distanceCm; // Stores the calculated distance in centimeters
};

#endif
```

`IMU` Class
This class manages the BNO055 Inertial Measurement Unit. It handles the initialization and calibration of the sensor and provides easy-to-use functions to get the robot's heading (direction). It can provide a standard heading (-180 to 180) or a continuous heading that keeps track of full rotations (e.g., 360, 450, etc.).
```cpp
#pragma once

#include <Adafruit_BNO055.h>
#include <Wire.h>

class IMU {
public:
    IMU(); // Constructor
    bool setup(); // Initializes and calibrates the BNO055 sensor
    void update(); // Reads the latest data from the sensor
    float getHeading(); // Returns the heading normalized to a -180 to 180 degree range
    float getHeadingRotating(); // Returns a continuous heading that increases/decreases past 360
    void reset(); // Sets the current heading as the new "zero" reference point

private:
    Adafruit_BNO055 _bno; // The sensor library object
    float _heading; // Stores the current calculated heading
    float _offset; // Stores the offset for the zero reference
    float _prevRawHeading; // Tracks the last raw reading to detect full rotations
    int _rotationCount; // Counts the number of full 360-degree rotations
};
```

`MotorController` Class
This class provides control over the main DC drive motor. It handles basic movements like forward, backward, and stop. It also includes a built-in PID controller to maintain a constant target speed, using feedback from the Encoder class.

```cpp
#ifndef MOTOR_CONTROLLER_H
#define MOTOR_CONTROLLER_H

#include <Arduino.h>
#include "config.h"
#include "Encoder.h" 

class MotorController {
public:
    // Constructor: sets the motor driver pins and links the encoder
    MotorController(int dir1_pin, int dir2_pin, int speed_pin , Encoder* encoder);
    void setup(); // Initializes the motor pins
    void forward(int speed); // Drives the motor forward at a given speed
    void backward(int speed); // Drives the motor backward at a given speed
    void move(int speed); // General move function (positive for forward, negative for backward)
    void stop(); // Lets the motor coast to a stop
    void stopBreak(int direction); // Actively brakes the motor

    void setTargetSpeed(float target); // Sets the desired speed for the PID controller
    void updatePID(); // Updates the motor's PWM based on the PID calculation

private:
    int _dir1_pin, _dir2_pin, _speed_pin; // Motor driver pins
    Encoder* _encoder; // Pointer to the encoder object for speed feedback

    // PID control variables
    float _targetSpeed;
    float _kp, _ki, _kd;
    float _prevError, _integral;
    int _currentPWM;
    unsigned long _lastPIDTime;
    float _prevDistance;
};

#endif // MOTOR_CONTROLLER_H
```

`PIDController` Class
This is a general-purpose PID (Proportional-Integral-Derivative) controller. We use it primarily for steering control, where it takes the target heading and the current heading as input, and calculates the necessary steering correction to minimize the error.

```cpp
#pragma once

class PIDController {
public:
    PIDController(); // Constructor
    void setup(float kp, float ki, float kd); // Initializes the controller with PID gains
    void setTunings(float kp, float ki, float kd); // Allows changing PID gains during runtime
    void setOutputLimits(float min, float max); // Clamps the output value (e.g., servo angle)
    void reset(); // Resets the integral and derivative terms
    float compute(float setpoint, float input); // Calculates the PID output based on a target and current value
    float geterror(); // Returns the last calculated error

private:
    float kp, ki, kd; // The PID gains (Proportional, Integral, Derivative)
    float prevError; // The error from the previous calculation
    float integral; // The accumulated error over time
    float outputMin, outputMax; // The minimum and maximum allowed output
    float error; // The current error
    unsigned long lastTime; // The timestamp of the last calculation
};
```

`SerialCommunicator` Class
This class is responsible for all communication between the ESP32 and the Raspberry Pi (or computer running the Python script). It listens for incoming serial data, parses the commands (like AVOID or TURN), and makes the values available to the main logic.
```cpp
#pragma once

#include <Arduino.h>
#include "core/Timer.h"

class SerialCommunicator
{
public:
    SerialCommunicator(); // Constructor

    void update(); // Must be called repeatedly to check for and process incoming data
    void clearSerialBuffer(); // Clears any pending data from the serial input
    bool getManeuverValues(float &distance, float &angle); // Gets the latest AVOID command values
    void resetManeuverValues(); // Resets the maneuver values after they have been used
    float getTurn(); // Gets the latest TURN command value (angle)
    void resetTurn(); // Resets the turn value after it has been used

private:
    static const uint16_t PACKET_SIZE = 5; // Defines the size of our communication packet

    // Variables to store the parsed command values
    float _distance;
    float _angle;
    float _turn;
    char _lastCommand;

    Timer timer;

    void processPacket(uint8_t *buffer); // Internal function to parse a raw data packet
};
```
`Steering` Class
A straightforward class to control the steering servo motor. It simplifies setting the steering angle and centering the wheels.

```cpp
#ifndef STEERING_H
#define STEERING_H

#include <ESP32Servo.h>
#include "config.h"

class Steering {
public:
    Steering(int servo_pin); // Constructor: sets the servo's pin number
    void setup(); // Attaches the servo object to its pin
    void setAngle(int angle); // Sets the steering servo to a specific angle
    void center(); // A helper function to set the steering to the center position (0 degrees)

private:
    Servo _servo; // The ESP32 servo library object
    int _servo_pin; // Stores the GPIO pin for the servo
};
#endif // STEERING_H
```

`Timer` Class
A simple utility for handling time-based events without using delay(), which would block the entire program. It can be used to check if a certain amount of time has passed.

```cpp
#pragma once

#include <Arduino.h>

class Timer {
public:
    Timer(); // Constructor
    void start(unsigned long duration_ms); // Starts a non-blocking timer for a specific duration
    bool isFinished(); // Returns true if the timer has finished
    void reset(); // Resets the timer
    static void wait(unsigned long duration); // A traditional blocking delay function

private:
    unsigned long _startTime; // The time when the timer was started
    unsigned long _duration; // The duration of the timer
    bool _running; // Flag to indicate if the timer is active
};
```

`TOFSensor` Class
This class manages the VL53L0X Time-of-Flight (TOF) distance sensor mounted on the rear of the robot. TOF sensors are very fast and accurate, making this perfect for the RESET state where the robot needs to position itself precisely against the back wall. It includes a simple averaging filter to stabilize readings.

```cpp
#ifndef TOF_SENSOR_H
#define TOF_SENSOR_H

#include <Arduino.h>
#include <Adafruit_VL53L0X.h>
#define TOF_FILTER_SIZE 2

class TOFSensor {
public:
    // Constructor: sets the sensor's shutdown pin and I2C address
    TOFSensor(uint8_t xshutPin, uint8_t i2cAddress = 0x30, uint16_t defaultDistance = 8000);

    bool begin(); // Initializes the VL53L0X sensor
    void update(); // Takes a new reading from the sensor and updates the filter
    bool isOutOfRange(); // Checks if the current reading is out of the sensor's range
    uint16_t getDistance(); // Returns the filtered distance in millimeters

private:
    uint8_t _xshutPin; // The pin used to enable/disable the sensor
    uint8_t _i2cAddress; // The I2C address for the sensor
    uint16_t _defaultDistance; // A default value to return if the reading is out of range
    
    // Variables for the averaging filter
    uint16_t _distanceBuffer[TOF_FILTER_SIZE];
    uint16_t _avgDistance;
    uint8_t _bufferIndex;
    bool _bufferFilled;

    Adafruit_VL53L0X _lox; // The sensor library object
    VL53L0X_RangingMeasurementData_t _measure; // A struct to hold the measurement data
};

#endif
```

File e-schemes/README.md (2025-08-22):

# WRO Future Engineer Car Project

This project is a smart robotic car designed for the **World Robot Olympiad (WRO) Future Engineer competition**. The car integrates a **Raspberry Pi 5**, **ESP32**, multiple sensors, actuators, a 12V battery pack, and a Pi Camera V3 to enable autonomous navigation, obstacle detection, and precise movement control.

---

## Electronic Section (Power and Sense Management)

This section describes all electronic components, their power management, sensors, actuators, and connections in the car system.

---

## 1. Components Overview

### Raspberry Pi 5
- **Purpose:** Main processor for high-level computations, vision processing, and communication.  
- **Why Used:** Handles complex algorithms like obstacle detection, path planning, and communicates with the ESP32 for motor and sensor control.  
- **Power Source:** 5V powerbank connected via USB to the ESP32 for power and serial communication.

### Raspberry Pi Camera V3
- **Purpose:** Captures video/images for obstacle detection and computer vision tasks.  
- **Why Used:** Enhances autonomous navigation with visual obstacle recognition and path tracking.  
- **Specs:** 12 MP, 4056×3040 still resolution, supports 60 fps video.  
- **Connection:** Directly connected to Raspberry Pi board.  

### ESP32 DevKit
- **Purpose:** Real-time control of motors, servos, and sensors.  
- **Why Used:** Provides low-latency processing for actuator control and sensor reading.  
- **Power Source:** USB from Pi.

### L298N Motor Driver
- **Purpose:** Drives DC motors with speed and directional control via PWM.  
- **Why Used:** Safely interfaces ESP32 with high-current motors.  
- **Power Source:** Directly from 12V battery pack.

### MG90 Servo Motor
- **Purpose:** Controls steering angle for the car.  
- **Why Used:** Provides precise angular motion for navigation.

### LM2596 Step-Down Voltage Regulator
- **Purpose:** Converts 12V battery voltage to lower voltages for microcontrollers and sensors.  
- **Why Used:** Ensures stable voltage and protects electronics.

### Ultrasonic Sensors (Front, Right, Left)
- **Purpose:** Detect obstacles and measure distances.  
- **Why Used:** Enables real-time obstacle avoidance.  
- **Power Supply:** 12V via LM2596 step-down.

### BNO055 IMU Sensor
- **Purpose:** Measures orientation, acceleration, and angular velocity.  
- **Why Used:** Provides accurate feedback for navigation, stabilization, and movement correction.  
- **Power Supply:** 3.3V from ESP32.  
- **Communication:** I2C.

### VL53L0X ToF Sensor
- **Purpose:** Measures precise distances using laser light.  
- **Why Used:** Provides short-range distance measurements for navigation and obstacle detection.  
- **Power Supply:** 3.3V from ESP32.  
- **Communication:** I2C.

### AS5600 Magnetic Encoder
- **Purpose:** Measures motor rotation and angular position with high precision.  
- **Why Used:** Enables precise tracking and control of wheel rotation.  
- **Power Supply:** 3.3V from ESP32.  
- **Communication:** I2C.

### 12V Battery Pack (3 × 18650 Li-ion) with BMS 3S
- **Purpose:** Supplies main power to PCB, motors, and sensors.  
- **Configuration:** 3 × 18650 cells in series (3S) → 12V nominal.  
- **Charging & Protection:** Equipped with **BMS 3S** for safe charging, overcharge/discharge protection, and stable 12V output.  
- **Connection:** Provides 12V to LM2596 and motor driver; integrated into PCB.  

### Control Button
- **Purpose:** Manual operation to start or stop the car.  
- **Why Used:** Provides a simple user interface for testing.

### Power Switch
- **Purpose:** Controls the 12V battery supply to the PCB.  
- **Why Used:** Allows safe powering on/off of all PCB-connected components.

---

## 2. System Architecture

The system architecture consists of two main controllers:

1. **Raspberry Pi 5**
   - Runs computer vision algorithms for obstacle detection using Pi Camera V3.
   - Sends high-level movement commands to ESP32 via USB serial communication.

2. **ESP32 DevKit**
   - Controls DC motors and servo for precise navigation.
   - Reads sensors (ultrasonic, ToF, IMU, AS5600) for feedback and obstacle avoidance.
   - Sends real-time sensor data to Raspberry Pi.

**Power Distribution:**
- 12V battery pack (3 × 18650 Li-ion with BMS 3S) → LM2596 step-down → ESP32 and sensors  
- ESP32 I2C sensors: 3.3V  
- Raspberry Pi 5: 5V powerbank → USB connection  
- Pi Camera V3: Powered through Pi board

---

## 3. Pin Configuration (ESP32)

| Component | Pin Number / Channel |
|---|---|
| Motor Speed (PWM) | 5 (channel 1, 30kHz, 8-bit) |
| Motor Direction 1 | 19 |
| Motor Direction 2 | 18 |
| Servo | 32 |
| Ultrasonic Front | 25 |
| Ultrasonic Right | 26 |
| Ultrasonic Left | 27 |
| Control Button | 15 |
| ToF Sensor (SHT_LOX)  | 16 |
| IMU Sensor (BNO055) | I2C (SDA/SCL) |
| AS5600 Encoder | I2C (SDA/SCL) |
| Pi Camera V3 | Connected to Raspberry Pi board |

---

## 4. Software Stack

- **Raspberry Pi 5:** Python 3, OpenCV for computer vision, serial communication with ESP32.  
- **ESP32 DevKit:** Arduino C++ firmware for motors, servos, and sensors.  
- **Libraries:** 
  - `Adafruit_BNO055` for IMU  
  - `VL53L0X` library for ToF sensor  
  - `Servo.h` and PWM libraries for motor and servo control

---

## 5. Calibration and Tuning

- **Servo Calibration:** Align center at 90°, set min/max pulse width (0–2000 µs)  
- **Motor PWM Tuning:** Recommended speed 200/255  
- **PID for Steering:** KP = 3.5  
- **Ultrasonic Sensors:** Test max distance = 200 cm, apply averaging filter  
- **IMU & Encoder:** Test rotation and angular feedback accuracy

---

## 6. Testing and Validation

- Obstacle detection range and response time  
- Servo angle precision and turning accuracy  
- Distance tracking using AS5600 encoder  
- Stability and heading using BNO055 IMU  
- Integration testing with Pi Camera obstacle detection

---

## 7. Challenges and Solutions

- **Ultrasonic Noise:** Solved with averaging filter  
- **Servo Jitter:** Adjusted PWM frequency  
- **USB Latency:** Optimized serial communication between Pi and ESP32  
- **Sensor Power Stability:** Ensured regulated 3.3V supply for I2C devices

---

## 8. Future Improvements

- Add AI-based path planning and object recognition  
- Integrate wireless control and telemetry  
- Implement battery monitoring and automated charging  
- Improve sensor fusion algorithms for smoother navigation

---

## 9. Quantity and Pricing (Estimates)

| Component | Quantity | Estimated Price (USD) | Notes |
|---|---|---|---|
| Raspberry Pi 5 | 1 | $80 | Powered by 5V powerbank |
| Raspberry Pi Camera V3 | 1 | $35 | Connected to Pi board |
| ESP32 DevKit | 1 | $12 | Real-time control |
| L298N Motor Driver | 1 | $6 | Dual motor driver |
| MG90 Servo Motor | 1 | $4 | Steering control |
| LM2596 Step-Down | 1 | $2 | Voltage regulation from 12V |
| BNO055 IMU Sensor | 1 | $15 | 3.3V supply |
| Ultrasonic Sensor | 3 | $3 each ($9 total) | 3.3V supply |
| VL53L0X ToF Sensor | 1 | $6 | 3.3V supply |
| AS5600 Encoder | 1 | $5 | Magnetic rotary encoder, I2C |
| 12V Battery Pack + BMS | 1 | $2 | 3 × 18650 Li-ion, BMS 3S, powers PCB & motors |
| Control Button | 1 | $1 | Manual control |
| Power Switch | 1 | $2 | Controls 12V battery to PCB |
| Misc. Wires & PCB | - | $10 | Connections & mounting |

**Total Estimated Cost:** ~$194  

---

## 10. Project Overview

This car is designed for:

- **Autonomous navigation:** Using ultrasonic, ToF sensors, and Pi Camera V3.  
- **Precise movement control:** Using DC motors, servo steering, IMU, and AS5600 encoder.  
- **Obstacle detection and avoidance:** Real-time detection with sensors and computer vision.  
- **Safe and flexible power management:** 12V battery pack with BMS and switch, 5V powerbank for Pi, 3.3V for I2C sensors.  
- **Future scalability:** Can integrate advanced AI algorithms and visual recognition using Raspberry Pi 5.

---

## 11. Common Problems and Troubleshooting

Even with careful assembly, robotics projects like this car may encounter common issues. Here’s a list of potential problems and solutions:

### 1. Raspberry Pi Not Powering On
- **Cause:** Insufficient power from the 5V powerbank or poor USB connection to ESP32.  
- **Solution:** Ensure the powerbank provides at least 3A output. Use a high-quality USB cable and check connections.

### 2. Pi Camera V3 Not Detected
- **Cause:** Incorrect ribbon cable connection or disabled camera interface.  
- **Solution:** Re-seat the ribbon cable, enable the camera in `raspi-config`, and reboot Pi.

### 3. Motors Not Responding
- **Cause:** Wrong wiring to L298N or incorrect PWM configuration.  
- **Solution:** Double-check motor wiring and verify ESP32 PWM channel and frequency settings.

### 4. Servo Jitter or Incorrect Steering
- **Cause:** PWM frequency mismatch or unstable voltage.  
- **Solution:** Ensure the servo receives stable voltage and adjust PWM frequency. Calibrate center position.

### 5. Ultrasonic Sensor Noise / False Readings
- **Cause:** Interference between sensors or environmental noise.  
- **Solution:** Apply averaging filters in software, separate trigger pins for each sensor, and test in a less reflective environment.

### 6. AS5600 Encoder Incorrect Readings
- **Cause:** Magnetic misalignment or I2C communication error.  
- **Solution:** Ensure magnet is correctly positioned, check I2C connections, and verify library usage.

### 7. IMU (BNO055) Drifting or Instability
- **Cause:** Improper calibration or power fluctuations.  
- **Solution:** Calibrate the IMU properly, ensure stable 3.3V supply, and avoid sudden shocks during operation.

### 8. USB Latency Between Pi and ESP32
- **Cause:** High data rate or inefficient serial communication.  
- **Solution:** Optimize serial protocol, reduce data frequency, and avoid sending unnecessary data.

### 9. VL53L0X ToF Sensor Inaccurate Distance
- **Cause:** Reflective surfaces or ambient light interference.  
- **Solution:** Avoid highly reflective surfaces, calibrate sensor for the specific environment.

### 10. PCB Power Issues
- **Cause:** Overloaded step-down regulator or loose connections.  
- **Solution:** Check current ratings, ensure proper soldering, and verify LM2596 output voltage.

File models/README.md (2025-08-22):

# Competition Car Design – WRO Future Engineer
**Team Name:** Bloody Hilux  

This document describes the design of our competition car, developed for the *WRO Future Engineer* challenge.  
The car was engineered to combine **speed, stability, precise turning, and efficiency**, using a balance between carefully selected components, optimized mechanics, and a lightweight chassis.

---

## 1. Motors & Selection
The car is powered by a **DC motor** with the following specifications:
- Maximum speed: **281 RPM**
- Maximum torque: **5 kgf·cm (~0.49 N·m)**

This motor was selected because it provides the best trade-off between torque and speed. It ensures:
- Strong performance in acceleration  
- Reliable top speed on straight tracks  
- Compatibility with the chosen gear ratio and wheel size  

By tuning the gear ratio (see below), we ensure that the motor provides both speed and enough torque to overcome track resistance.

---

## 2. Drivetrain & Gear Ratio
The drivetrain is the link between the motor and the wheels. It consists of:
- **Gear ratio:** 2.2:1  
  - This means for every 2.2 motor rotations, the wheel completes 1 rotation.  
  - This increases **wheel speed** but slightly reduces torque, a trade-off suitable for flat tracks.
- **Differential system:** A 1:1 bevel gear system with 4 internal gears  
  - Allows left and right wheels to rotate at different speeds while turning.  
  - Minimizes wheel slip and improves cornering stability.
- **Bearings:** 12 precision ball bearings  
  - Reduce friction  
  - Increase efficiency and smoothness of drivetrain  

This system ensures **power efficiency and stability** while turning.

---

## 3. Speed Calculation
Given the motor speed and wheel diameter, we calculate top speed:

- Motor RPM: 281  
- Wheel RPM = 281 × 2.2 ≈ 618  
- Wheel diameter = 59 mm → circumference ≈ 0.185 m  

---

## 4. Power Calculation
- Motor torque: \(T_\{motor} = 0.49~\{N·m}\)  
- Motor angular velocity: \(\omega_\{motor} = 29.41~\{rad/s}\)  

**At the wheels (after gear ratio):**
- Torque: \(T_\{wheel} = \frac{0.49}{2.2} \approx 0.223~\{N·m}\)  
- Angular velocity: \(\omega_\{wheel} = 29.41 \times 2.2 \approx 64.7~\{rad/s}\)  
- Power: \(P_\{wheel} = 0.223 \times 64.7 \approx 14.4~\{W}\)  

---

## 5. Torque & Linear Force
- Wheel radius: \(r = 0.0295~\{m}\)  
- Torque at wheels: \(T_\{wheel} = 0.223~\{N·m}\)  

---

## 6. Steering Mechanism (Ackermann)
The steering system follows **Ackermann geometry**:
- Inner wheel angle: **65°**  
- Outer wheel angle: **38°**  

This ensures that:
- Each wheel follows the correct turning radius.  
- Tire drag is minimized.  
- Cornering becomes precise and stable.  

The steering is controlled by a **single servo motor**, connected with a durable linkage system.

---

## 7. Chassis & Structure
- **Weight:** ~1.25 – 1.3 kg  
- **Dimensions:** 23 cm (length) × 20 cm (width)  
- **Design:** Double plexiglass plates with 3D-printed support components  
- **Balance:** Components are placed to keep the center of gravity low  

This combination provides both **durability and lightness**, key for competitions where stability and speed are critical.

---

## 8. Assembly & CAD Design
All custom parts were designed in **CAD software** and manufactured with **3D printing** for precision.  
Features:
- Modular design → quick part replacement  
- Optimized geometry → reduced friction  
- Bearings and inserts → increased durability  

---

## 9. Summary
To summarize, our car balances mechanics, power, and control:

- **Motor & Gear Ratio** → Provide high speed while maintaining torque  
- **Differential** → Smooth turning and power distribution  
- **Ackermann Steering** → Precision and minimal drag in corners  
- **Chassis** → Lightweight, low center of gravity, strong structure  
- **Bearings** → Smooth motion with reduced friction  
- **Calculated Performance**:  
  - Max speed ≈ 1.91 m/s (~6.9 km/h)  
  - Power ≈ 14.4 W  
  - Wheel torque ≈ 0.223 N·m  
  - Linear force ≈ 7.56 N

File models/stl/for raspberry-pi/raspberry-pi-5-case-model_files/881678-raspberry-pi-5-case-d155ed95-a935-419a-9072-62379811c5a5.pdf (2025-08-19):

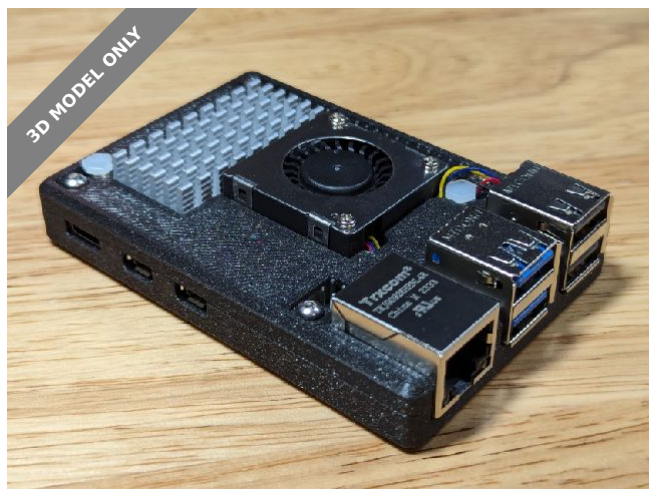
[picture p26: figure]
3D MODEL ONLY

## Summary

A case for a raspberry pi 5 with active cooler

Gadgets (https://printables.com/model?categoryId=21) > Computers (https://printables.com/model?categoryId=27)

Tags: | case | raspberry | raspberrypi | raspberrypi5
raspberry5case | activecooler

While slicing, I used supports for the SD card slot and the screw holes but it's possible they may not all need supports.

After printing, poke holes through the thin top layer that is covering the screw holes.

Use care when adding the lid to not pinch the active cooler wires.

Original Author: @jeraff24_382585

## This remix is based on

Bobby Greenan (https://printables.com/@BobbyGreenan_1866414)

## Raspberry Pi 5 Case

VIEW IN BROWSER (https://printables.com/model/881678-raspberry-pi-5-case)

updated 16. 5. 2024 | published 16. 5. 2024

## Model files

## Other files

Slim Case for Raspberry Pi 5 with Active Cooler by jeraff24 (https://www.thingiverse.com/thing:6460985)

- files | 2 files

## License

This work is licensed under a
Creative Commons (4.0 International License)

Attribution-NonCommercial (http://creativecommons.org/licenses/by-nc/4.0/)

pi5-case-base.stl

pi5-case-lid.stl

license.txt

readme.txt

✖ | Sharing without ATTRIBUTION
✔ | Remix Culture allowed
✖ | Commercial Use
✖ | Free Cultural Works
✖ | Meets Open Definition

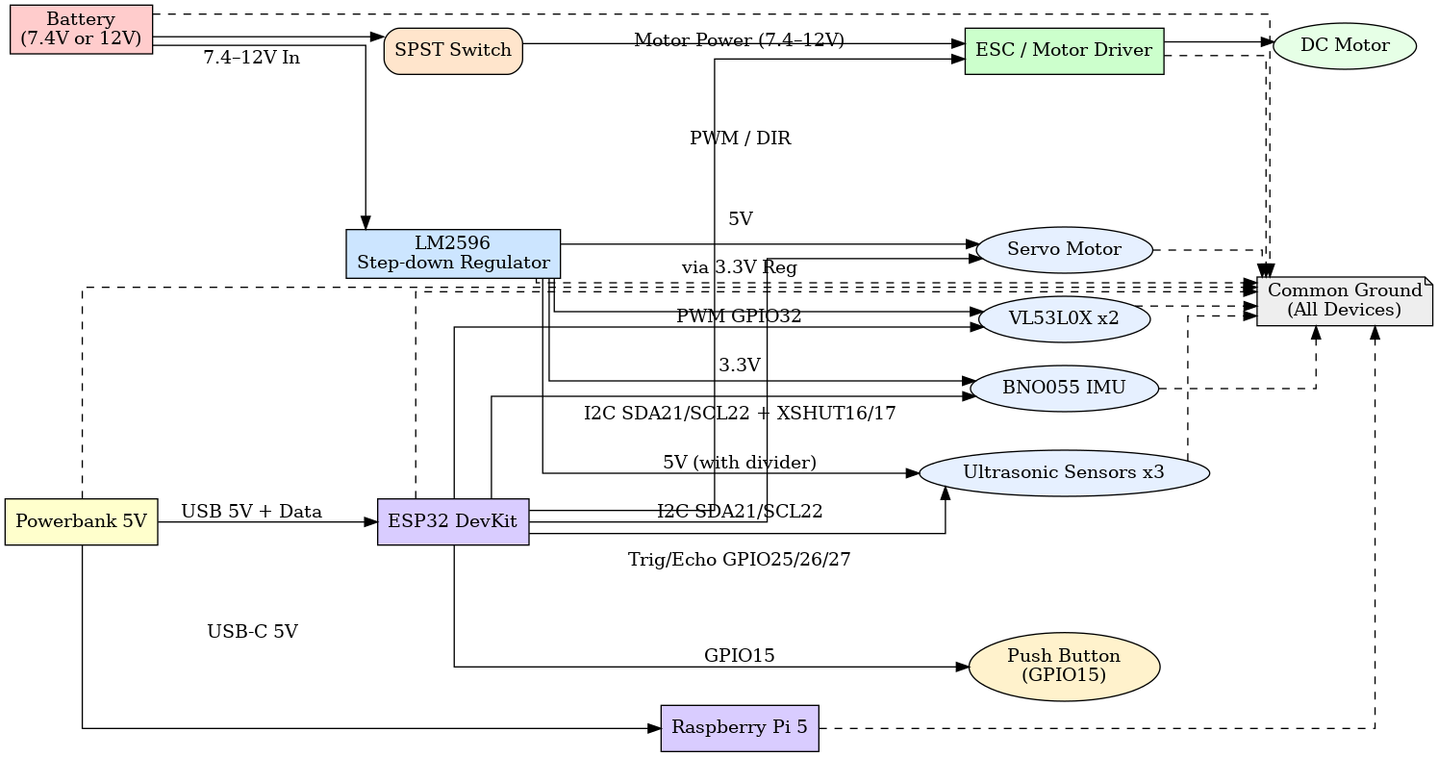
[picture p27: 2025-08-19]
e-schemes/pi_esp32_schematic.png

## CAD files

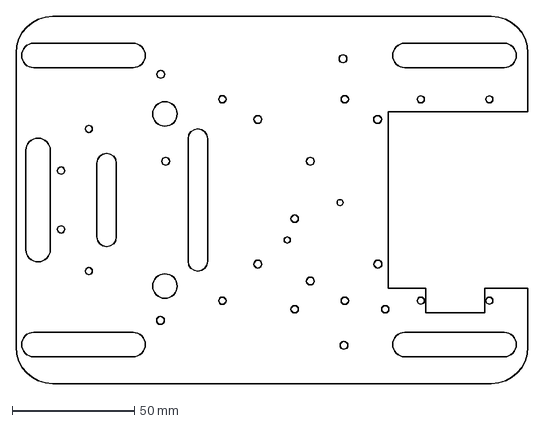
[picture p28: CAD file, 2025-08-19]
models/dxf/plate 2.DXF
209.0 x 150.0 mm

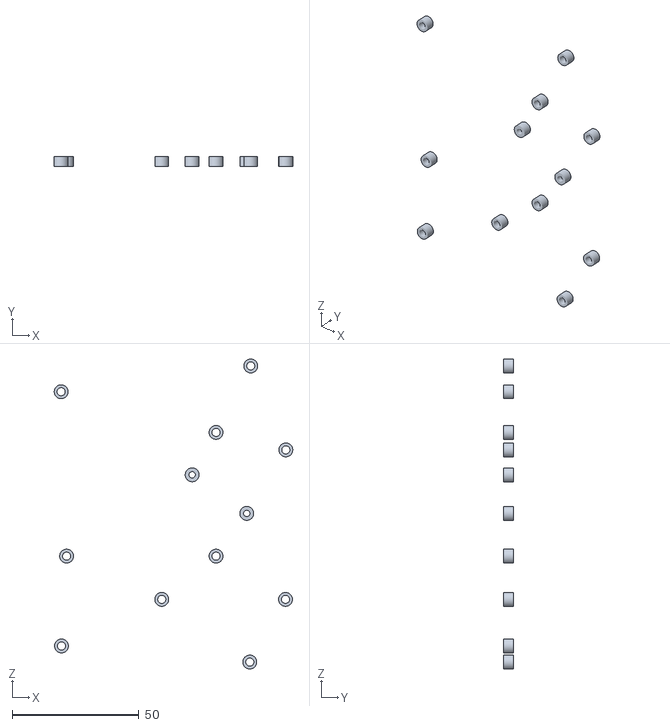
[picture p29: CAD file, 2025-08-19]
models/stl/battery and pcb/pcb base.STL
94.3 x 4.00 x 122.5

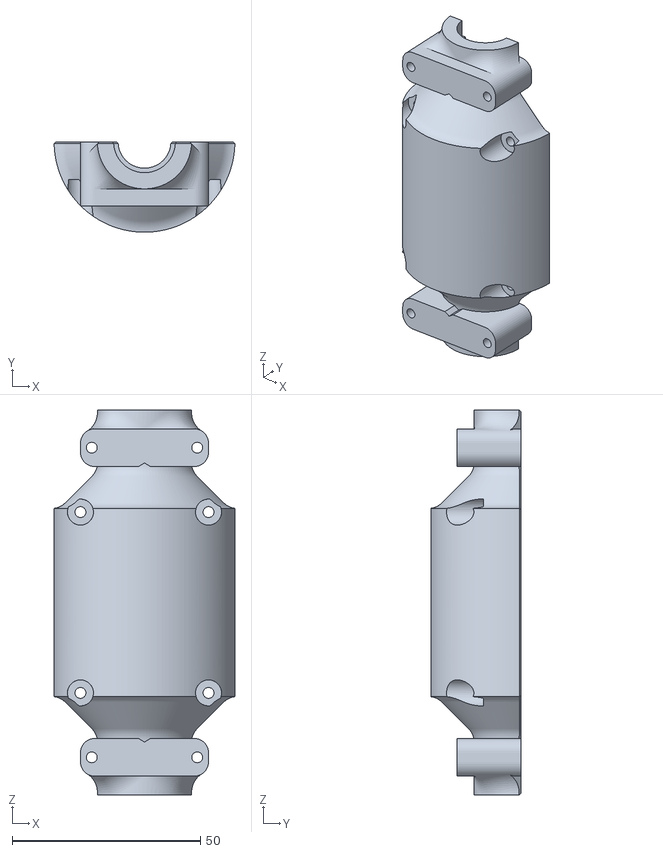
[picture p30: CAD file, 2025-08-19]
models/stl/differentail/differential pro basev2025.STL
48.0 x 24.0 x 102.2

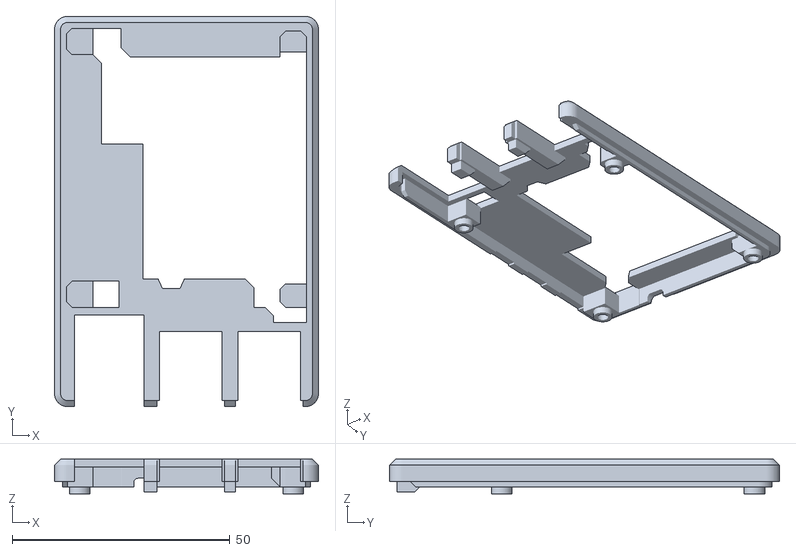
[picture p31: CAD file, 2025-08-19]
models/stl/for raspberry-pi/raspberry-pi-5-case-model_files/files/pi5-case-lid.stl
60.6 x 89.6 x 8.00

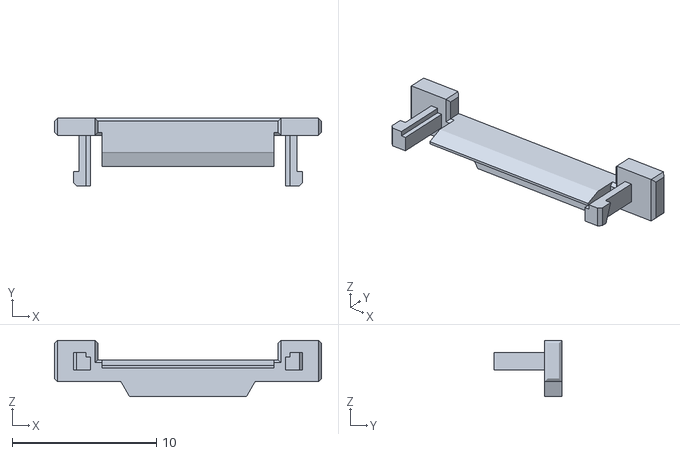
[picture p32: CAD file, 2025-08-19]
models/stl/for raspberry-pi/Vertical_Type_FPCFFC_connector[1].STL
18.5 x 4.68 x 3.90

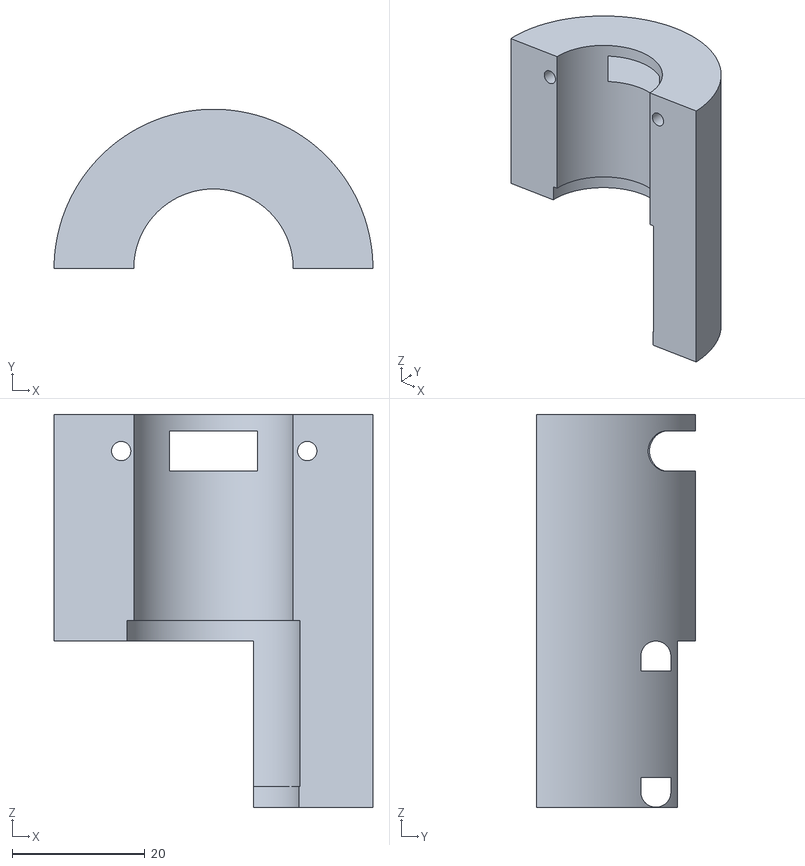
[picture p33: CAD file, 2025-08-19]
models/stl/senssor/tof base.STL
48.0 x 24.0 x 59.1

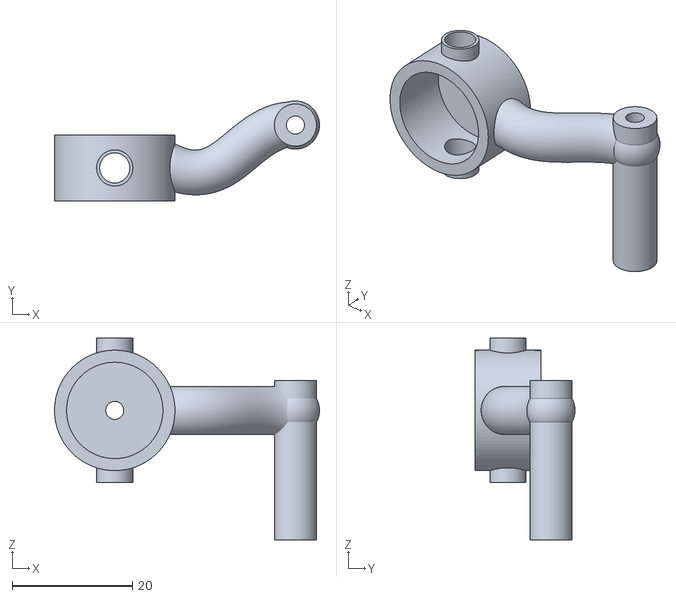
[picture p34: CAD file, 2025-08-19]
models/stl/ultra steering/steering weel link left2.STL
44.0 x 16.6 x 33.5

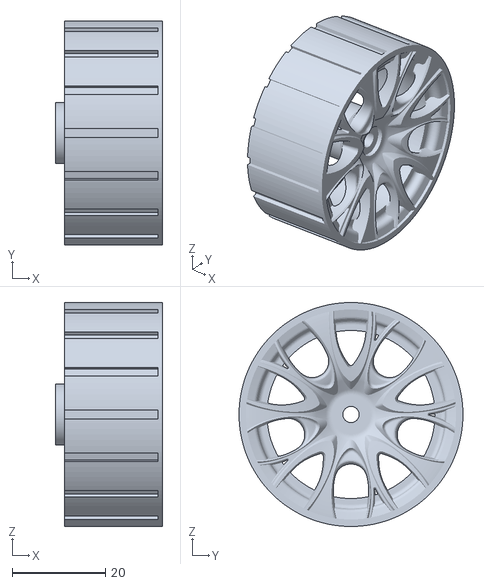
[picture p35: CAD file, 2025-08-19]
models/stl/wheels/back wheel rime2 .STL
23.0 x 48.0 x 48.0

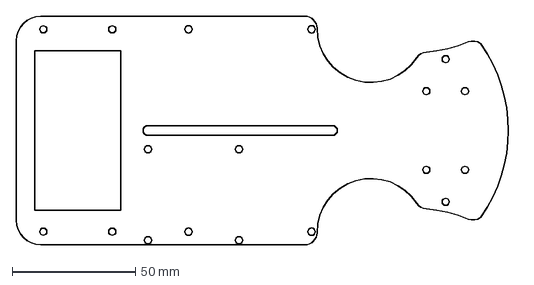
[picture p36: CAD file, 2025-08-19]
models/dxf/edit plate1.DXF
203.8 x 93.0 mm

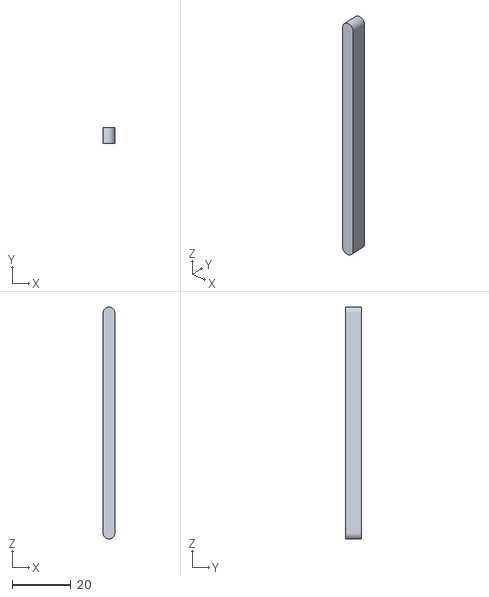
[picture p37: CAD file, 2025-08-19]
models/stl/battery and pcb/battery case21321.STL
4.00 x 5.40 x 79.0

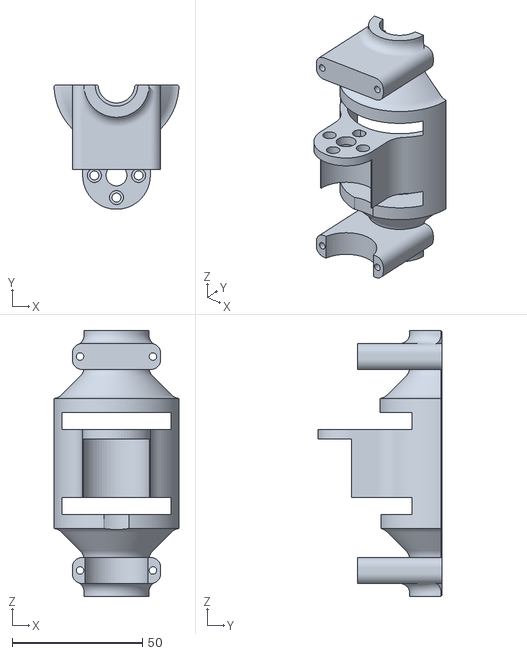
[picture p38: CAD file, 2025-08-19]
models/stl/differentail/differential pro base2 v20255.STL
48.0 x 47.8 x 102.2

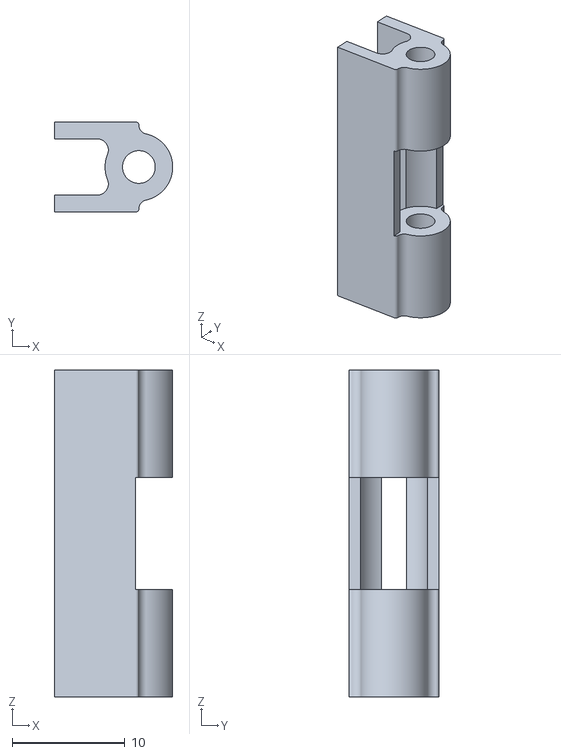
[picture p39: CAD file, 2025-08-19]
models/stl/for raspberry-pi/camera mount.STL
10.5 x 8.00 x 29.0

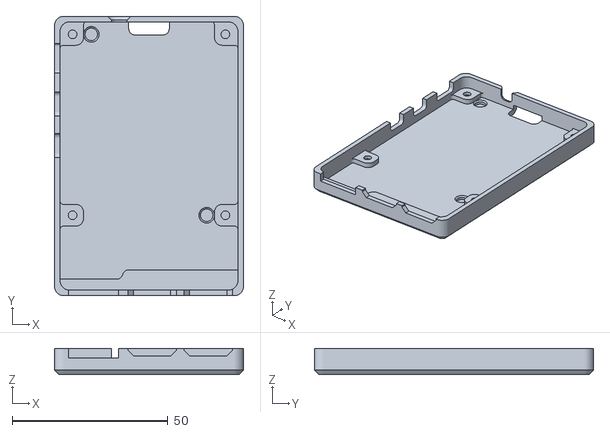
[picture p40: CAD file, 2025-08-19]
models/stl/for raspberry-pi/raspberry-pi-5-case-model_files/files/pi5-case-base.stl
60.6 x 89.6 x 8.40

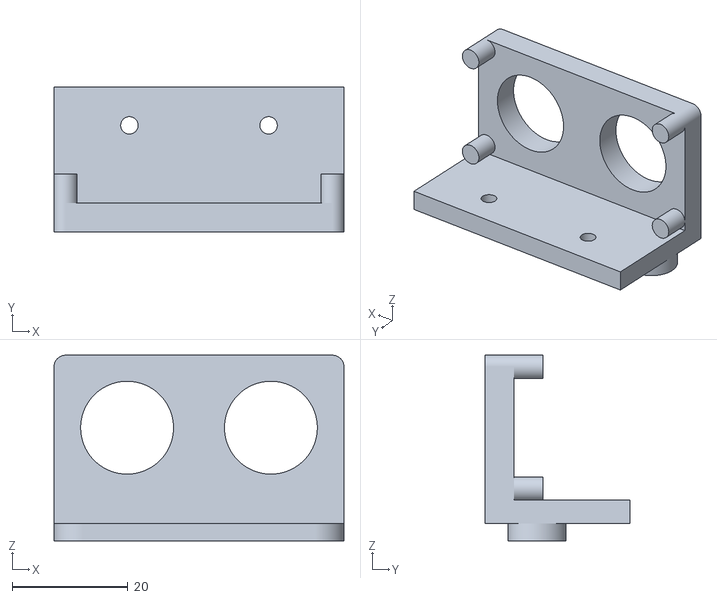
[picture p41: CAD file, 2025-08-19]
models/stl/senssor/ultrasonic 3.STL
50.0 x 25.0 x 32.0

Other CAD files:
models/stl/ultra steering/steering wheel link2.STL
models/stl/wheels/front wheel rime 2.STL
models/stl/battery and pcb/battery case22.STL
models/stl/differentail/helical gear_4_iso edit12.STL
models/dxf/for old steering/old plate.DXF
models/stl/differentail/base gear.STL
models/stl/for raspberry-pi/camera hing.STL
models/stl/senssor/encoder holder.STL
models/stl/senssor/magnet hub.STL
models/stl/senssor/ultrasonic 2.STL
models/stl/ultra steering/sterring test.STL

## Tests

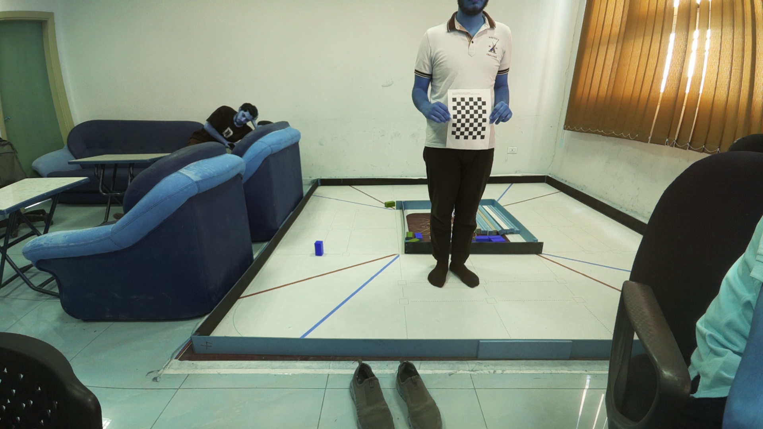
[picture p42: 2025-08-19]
src/camera-vision/calibration_images/calib_20250703_154638.jpg

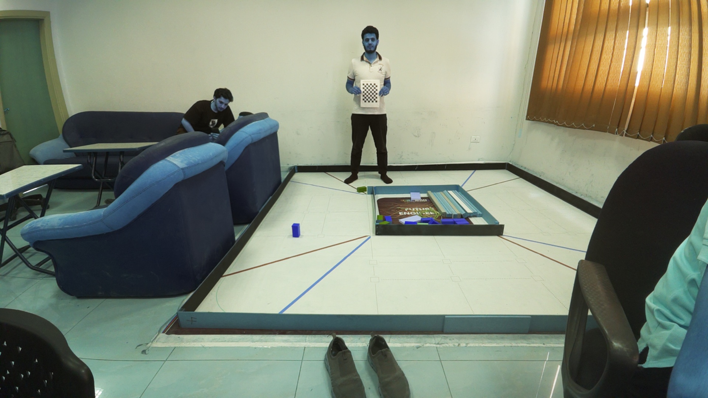
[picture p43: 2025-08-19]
src/camera-vision/calibration_images/calib_20250703_154708.jpg

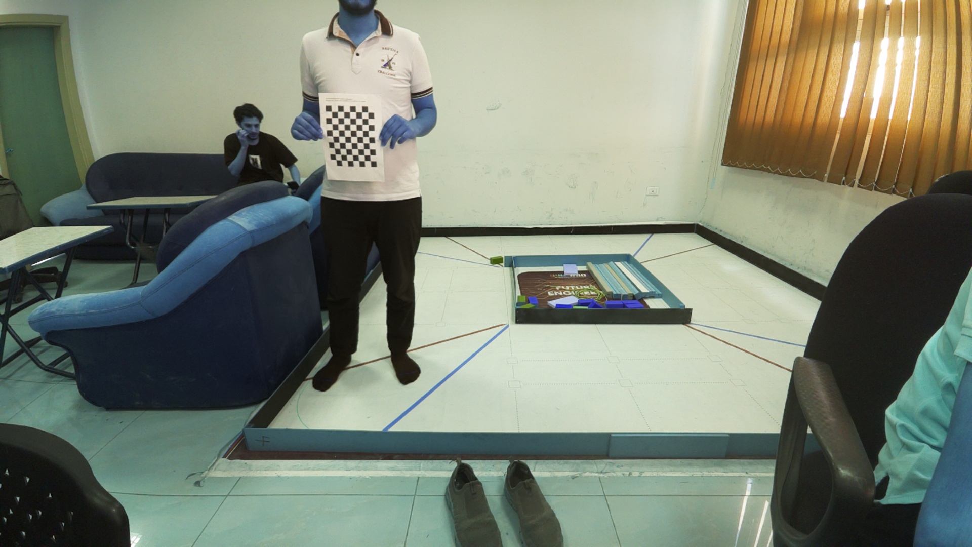
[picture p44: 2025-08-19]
src/camera-vision/calibration_images/calib_20250703_154742.jpg

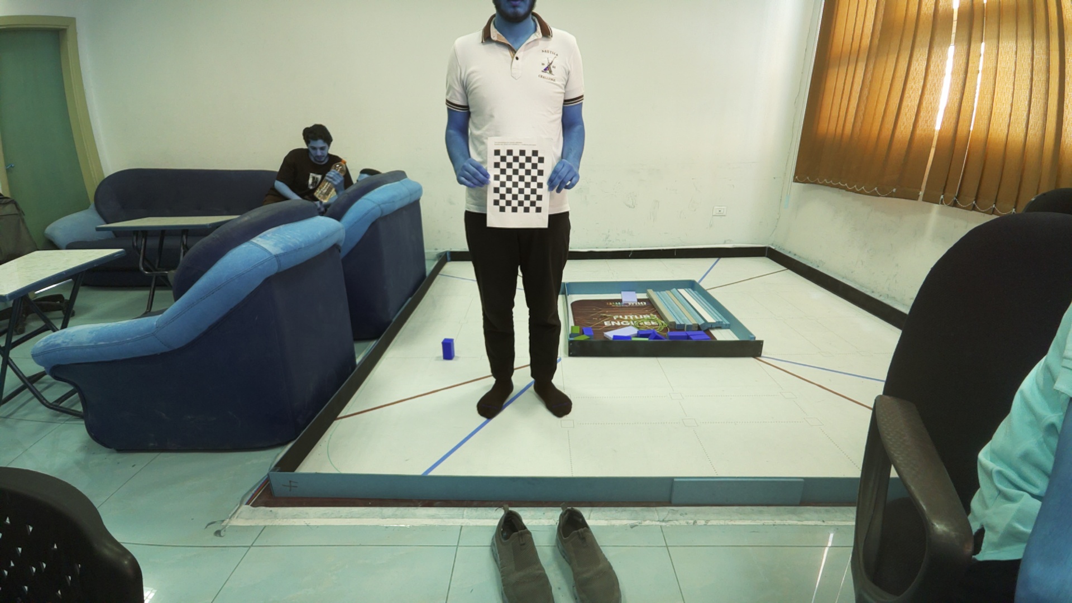
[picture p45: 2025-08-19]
src/camera-vision/calibration_images/calib_20250703_154633.jpg

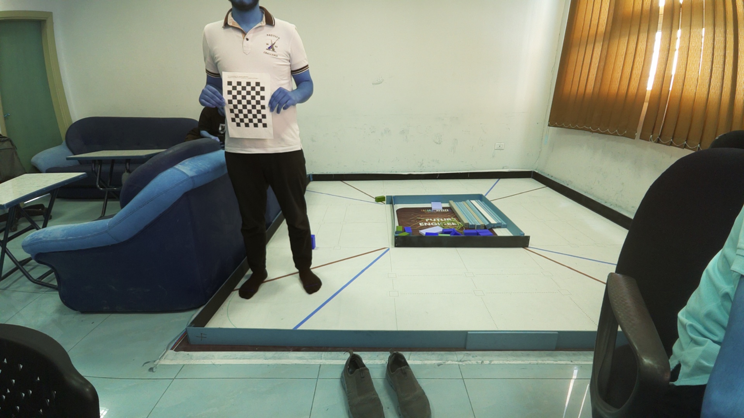
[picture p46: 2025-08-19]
src/camera-vision/calibration_images/calib_20250703_154723.jpg

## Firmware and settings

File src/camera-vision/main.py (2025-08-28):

import serial # pyright: ignore[reportMissingModuleSource]
import time
import cv2
import numpy as np
import struct
from camera_module import Camera
import json
from pathlib import Path


from enum import Enum

class OperationMode(Enum):
    HEADLESS = 'headless'         # No camera stream, just Arduino logic
    CAMERA_ONLY = 'camera_only'   # Camera stream only, no Arduino
    FULL = 'full'                 # Camera + Arduino
    
class Cooldown:
    def __init__(self, cooldown_time: float):
        self.cooldown_time = cooldown_time
        self.last_triggered = 0.0

    def ready(self) -> bool:
        return (time.time() - self.last_triggered) >= self.cooldown_time

    def reset(self):
        self.last_triggered = time.time()


class ObstacleDetector:
    def __init__(self, mode=OperationMode.HEADLESS, serial_port='/dev/ttyUSB0'):
        # Configuration
        self.mode = mode
        self.SERIAL_PORT = serial_port
        self.BAUDRATE = 115200
        self.PROFILES_FILE = "Hlba_rqm1.json"
        self.KNOWN_OBSTACLE_HEIGHT_CM = 10.0
        self.FOCAL_LENGTH = 570.0
        self.MAX_AREA = 3000.0
        self.last_turn_time = 0  # timestamp of the last detected turn
        self.detect_turn_cooldown = 6   # seconds to wait before detecting a new turn
        self.turn_detection_cooldown = Cooldown(6)
        self.wide_roi_cooldown = Cooldown(5)
        self.movedPoint = 5
        self.first_turn_detected = False
        self.persistent_turn_direction = None

        # State variables
        self.camera = None
        self.arduino = None

        # Initialize hardware and calibration
        self.initialize_camera()

        # Only initialize serial in production mode
        if self.mode is not OperationMode.CAMERA_ONLY:
            self.initialize_serial()
            
        # Color profiles
        self.COLOR_PROFILES = {}
        self.load_color_profiles()

    def load_color_profiles(self, filename=None):
        if filename is None:
            filename = self.PROFILES_FILE
        filename = "saved_profiles/" + filename
        try:
            with open(filename, 'r') as f:
                data = json.load(f)
            profiles = data.get("profiles", {})
            for color, p in profiles.items():
                self.COLOR_PROFILES[color] = {
                    'lower': np.array(p['lower']),
                    'upper': np.array(p['upper']),
                    'offset_adjust': p['offset_adjust']
                }
            print(f"Loaded color profiles from {filename}")
        except Exception as e:
            print("\033[1;31m" + "WARNING: Color profile file '{}' not found! Falling back to default profiles.".format(self.PROFILES_FILE) + "\033[0m")
            print(f"Error loading color profiles: {e}. Using default profiles.")
            # Fallback to hardcoded defaults
            self.COLOR_PROFILES = {
                'red': {
                    'lower': np.array([0, 163, 144]),
                    'upper': np.array([255, 216, 255]),
                    'offset_adjust': 20
                },
                'green': {
                    'lower': np.array([0, 0, 121]),
                    'upper': np.array([252, 104, 255]),
                    'offset_adjust': -20
                },
                'orange': {
                    'lower': np.array([0, 109, 82]),
                    'upper': np.array([255, 171, 121]),
                    'offset_adjust': 90
                },
                'blue': {
                    'lower': np.array([194, 114, 155]),
                    'upper': np.array([255, 180, 255]),
                    'offset_adjust': -90
                }
            }

    def initialize_camera(self):
        """Set up the camera hardware"""
        self.camera = Camera()
        print("Camera initialized.")

    def initialize_serial(self):
        """Set up serial communication with Arduino (production only)"""
        try:
            self.arduino = serial.Serial(
                port=self.SERIAL_PORT,
                baudrate=self.BAUDRATE,
                timeout=0.1
            )
            print(f"Serial connection established on {self.SERIAL_PORT}.")
            self.arduino.write(b'TEST')
            self.arduino.flush()
        except serial.SerialException as e:
            print(f"Serial error: {str(e)}")
            self.arduino = None

    def detect_color(self, lab_frame, color_name):
        """Detect specific color in LAB space"""
        profile = self.COLOR_PROFILES[color_name]
        mask = cv2.inRange(lab_frame, profile['lower'], profile['upper'])
        kernel = np.ones((5, 5), np.uint8)
        mask = cv2.morphologyEx(mask, cv2.MORPH_CLOSE, kernel)
        mask = cv2.morphologyEx(mask, cv2.MORPH_OPEN, kernel)
        return mask

    def find_largest_contour(self,mask, min_area=3000, max_area=100000):
        """
        Find the largest rectangle-like contour in a mask.
        Returns the contour if found, otherwise None.
        """
       
        if mask is None:
            return None

    
        if len(mask.shape) == 3:
            mask = cv2.cvtColor(mask, cv2.COLOR_BGR2GRAY)

    
        mask = mask.astype(np.uint8)

        contours, _ = cv2.findContours(mask, cv2.RETR_TREE, cv2.CHAIN_APPROX_SIMPLE)
        valid_contours = []

        for contour in contours:
            contour_area = cv2.contourArea(contour)
            if contour_area < min_area or contour_area > max_area:
                continue

            x, y, w, h = cv2.boundingRect(contour)
            # Check aspect ratio (width < height < 3*width)
            if w >= h or h > 3 * w:
                continue

            # Approximate contour to polygon and check for rectangle
            peri = cv2.arcLength(contour, True)
            approx = cv2.approxPolyDP(contour, 0.02 * peri, True)
            if len(approx) >= 4 and len(approx)<=8:
                valid_contours.append(contour)

        if not valid_contours:
            return None

        # Return the largest valid contour
        largest_contour = max(valid_contours, key=cv2.contourArea)
        return largest_contour



    def calculate_distance(self, pixel_height):
        """Calculate distance to object"""
        return (self.KNOWN_OBSTACLE_HEIGHT_CM * self.FOCAL_LENGTH) / pixel_height if pixel_height else 0

    def calculate_maneuver(self, frame_shape, bounding_rect, distance_cm, offset_adjust):
        """Calculate movement parameters"""
        x, y, w, h = bounding_rect
        obj_center_x = x + w / 2
        frame_center_x = frame_shape[1] / 2

        pixel_offset = obj_center_x - frame_center_x
        cm_per_pixel = self.KNOWN_OBSTACLE_HEIGHT_CM / h
        offset_x_cm = (pixel_offset * cm_per_pixel) + offset_adjust

        tendon = np.sqrt(offset_x_cm**2 + distance_cm**2)
        angle = np.arctan2(offset_x_cm, distance_cm)
        turn_angle = np.degrees(angle) 

        return tendon, turn_angle

    def process_obstacle(self, contour, frame_rgb, color_type):
        """Process detected obstacle and optionally send commands"""
        profile = self.COLOR_PROFILES[color_type]
        x, y, w, h = cv2.boundingRect(contour)
        distance = self.calculate_distance(h) - self.movedPoint
        travel_dist, turn_angle = self.calculate_maneuver(
            frame_rgb.shape, (x, y, w, h), distance, profile['offset_adjust']
        )

        

        # Annotate frame for visualization
        if self.mode is not OperationMode.HEADLESS:
            info_text = f"{color_type.upper()}: {distance:.1f}cm, {turn_angle:.1f}deg"
            cv2.rectangle(frame_rgb, (x, y), (x + w, y + h), (0, 255, 0), 2)
            cv2.putText(frame_rgb, info_text, (x, y - 10),
                        cv2.FONT_HERSHEY_SIMPLEX, 0.7, (0, 255, 0), 2)

        # Only send commands in production mode
        if (self.mode is not OperationMode.CAMERA_ONLY) and travel_dist <= 80:
            self.send_command('AVOID', travel_dist , turn_angle)

        print(
            f"{color_type.upper()}: Dist={travel_dist:.1f}cm, Angle={turn_angle:.1f}deg")
        return True

    def send_command(self, cmd_type, value1=0, value2=0):
        """
        Send a structured command to the Arduino.
        cmd_type: str ('AVOID' or 'TURN')
        value1, value2: float values (interpreted as tenths of units)
        """
        if self.arduino is None:
            return

        try:
            if cmd_type == 'AVOID':
                # Send both distance and angle
                header = b'A'
                val1 = int(round(value1 * 10))
                val2 = int(round(value2 * 10))
            elif cmd_type == 'TURN':
                # Send angle and dummy value (0)
                header = b'T'
                val1 = int(round(value1 * 10))
                val2 = 0
            else:
                print(f"Unknown command type: {cmd_type}")
                return

            packet = struct.pack('<chh', header, val1, val2)  # 5 bytes
            self.arduino.write(packet)
            self.arduino.flush()

        except (serial.SerialException, OSError) as e:
            print(f"ERROR: Failed to send command: {e}")
            self.arduino.close()
            self.arduino = None

    def capture_frame(self):
        """Capture and prepare a frame from camera"""
        frame = self.camera.capture_frame()
        return cv2.cvtColor(frame, cv2.COLOR_BGR2RGB)

    def detect_obstacles(self, frame_rgb):
        """Detect obstacles in a frame"""

        # Match calibration preprocessing
        frame_bgr = cv2.cvtColor(frame_rgb, cv2.COLOR_RGB2BGR)
        lab = cv2.cvtColor(frame_bgr, cv2.COLOR_BGR2LAB)
        lab = cv2.GaussianBlur(lab, (7, 7), 0)
        l, a, b = cv2.split(lab)
        clahe = cv2.createCLAHE(clipLimit=3.0, tileGridSize=(8, 8))
        cl = clahe.apply(l)
        frame_lab = cv2.merge((cl, a, b))

        # Detect both colors
        contours = {}
        for color in ['red', 'green']:
            mask = self.detect_color(frame_lab, color)
            contours[color] = self.find_largest_contour(mask)
            

        return contours

    def crop_frame(self, frame, x_ratio=0.25, y_ratio=0.25, width_ratio=0.5, height_ratio=0.5):
        """
        Crop the frame to a region of interest (ROI) using relative coordinates.

        Args:
            frame_rgb (np.ndarray): The input RGB frame.
            x_ratio (float): Horizontal start position as a fraction of frame width.
            y_ratio (float): Vertical start position as a fraction of frame height.
            width_ratio (float): Width of ROI as a fraction of frame width.
            height_ratio (float): Height of ROI as a fraction of frame height.

        Returns:
            np.ndarray: Cropped frame (ROI).
        """
        height, width, _ = frame.shape

        roi_left = int(width * x_ratio)
        roi_top = int(height * y_ratio)
        roi_width = int(width * width_ratio)
        roi_height = int(height * height_ratio)

        roi_right = min(roi_left + roi_width, width)
        roi_bottom = min(roi_top + roi_height, height)

        if self.mode is not OperationMode.HEADLESS:
            cv2.rectangle(frame, (roi_left, roi_top),
                            (roi_right, roi_bottom), (255, 255, 0), 2)

        return frame[roi_top:roi_bottom, roi_left:roi_right]

    def find_dominant_obstacle(self, contours):
        """Determine which obstacle is most prominent"""
        dominant_color = None
        max_area = 0

        for color, contour in contours.items():
            if contour is not None:
                area = cv2.contourArea(contour)
                if area > max_area:
                    max_area = area
                    dominant_color = color

        return dominant_color

    def detect_turn(self, frame_rgb):
        """
        Detect turn direction based on the percentage of orange or blue in a vertical ROI.
        This avoids contours and simply measures pixel presence.
        """
        roi = self.crop_frame(frame_rgb, 0.375, 0.7, 0.25, 0.2)
    
        # Match calibration color preprocessing
        roi_bgr = cv2.cvtColor(roi, cv2.COLOR_RGB2BGR)
        lab = cv2.cvtColor(roi_bgr, cv2.COLOR_BGR2LAB)
        l, a, b = cv2.split(lab)
        clahe = cv2.createCLAHE(clipLimit=3.0, tileGridSize=(8, 8))
        cl = clahe.apply(l)
        frame_lab = cv2.merge((cl, a, b))
    
        turn_map = {'blue': 'LEFT', 'orange': 'RIGHT'}
        debug_positions = {'blue': 30, 'orange': 60}
    
        for color in turn_map:
            mask = self.detect_color(frame_lab, color)
            pixel_ratio = np.sum(mask > 0) / mask.size
    
            if self.mode is not OperationMode.HEADLESS:
                cv2.putText(frame_rgb, f"{color.upper()} RATIO: {pixel_ratio:.2f}",
                            (10, debug_positions[color]), cv2.FONT_HERSHEY_SIMPLEX,
                            0.6, (255, 255, 255), 2)
    
            if pixel_ratio > 0.1:
                turn_detected = turn_map[color]
                print(f"TURN DETECTED: {turn_detected}")
    
                if self.mode is not OperationMode.HEADLESS:
                    cv2.putText(frame_rgb, f"TURN DETECTED: {turn_detected}",
                                (10, frame_rgb.shape[0] - 20), cv2.FONT_HERSHEY_SIMPLEX,
                                0.8, (0, 255, 255), 2)
    
                return turn_detected


        return None

    def handle_turn_detection(self, frame_rgb):
        """Detect first turn based on color, then persist that direction."""
        # If cooling down, skip detection unless in debug mode
        if not self.turn_detection_cooldown.ready() and self.mode is not OperationMode.CAMERA_ONLY:
            return

        direction = self.detect_turn(frame_rgb)
        if not self.first_turn_detected:
            if direction:
                # Store the first detected direction
                self.persistent_turn_direction = direction
                self.first_turn_detected = True
                print(f"First turn direction locked: {direction}")
                
        else:
            if direction:
                direction = self.persistent_turn_direction
                angle = -90 if direction == 'LEFT' else 90
                if self.mode is not OperationMode.CAMERA_ONLY:
                    self.send_command('TURN', angle)
                self.turn_detection_cooldown.reset()
                self.wide_roi_cooldown.reset()


    def process_frame(self , mode='rgb'):
        """Process a single frame"""
        frame_rgb = self.capture_frame()
        
        if not self.wide_roi_cooldown.ready():
        # Shrink the ROI to avoid false positives
            obstacle_roi_rgb = self.crop_frame(frame_rgb, 0.25, 0.07, 0.5, 0.8)
        else:
        # Full-size ROI
            obstacle_roi_rgb = self.crop_frame(frame_rgb, 0.1, 0.07, 0.8, 0.7)

        contours = self.detect_obstacles(obstacle_roi_rgb)
        dominant_color = self.find_dominant_obstacle(contours)
        
        

        if dominant_color:
            self.process_obstacle(
                contours[dominant_color],
                obstacle_roi_rgb,
                dominant_color
            )

        self.handle_turn_detection(frame_rgb)

        if mode == 'mask':
            lab_frame = cv2.cvtColor(cv2.cvtColor(obstacle_roi_rgb, cv2.COLOR_RGB2BGR), cv2.COLOR_BGR2LAB)
            red_mask = self.detect_color(lab_frame, 'red')
            green_mask = self.detect_color(lab_frame, 'green')
            combined_mask = cv2.bitwise_or(red_mask, green_mask)
            return cv2.cvtColor(combined_mask, cv2.COLOR_GRAY2BGR)  # Convert to 3-channel for display
        else:
            return frame_rgb


    def run_processing_loop(self):
        """Main processing loop for production"""
        print("Starting obstacle detection in PRODUCTION mode...")
        try:
            while True:
                # Process frame without visualization
                self.process_frame()
                time.sleep(0.08)
        except KeyboardInterrupt:
            print("\nStopping detection...")
        finally:
            if self.camera:
                self.camera.stop()
            if self.arduino:
                self.arduino.close()


# =================================================================
# Web Application (Debugging Only)
# =================================================================
def create_flask_app(detector):
    from flask import Flask, Response,request

    app = Flask(__name__)

    def generate_frames(mode='rgb'):
        """Video streaming generator for debugging"""
        while True:
            frame = detector.process_frame(mode=mode)
            success, encoded_frame = cv2.imencode(".jpg", frame)
            if success:
                yield (b'--frame\r\n'
                       b'Content-Type: image/jpeg\r\n\r\n' +
                       bytearray(encoded_frame) + b'\r\n')
            time.sleep(0.08)

    @app.route('/video_feed')
    def video_feed():
        mode = request.args.get('mode', 'rgb')
        return Response(generate_frames(mode),
                    mimetype='multipart/x-mixed-replace; boundary=frame')

    @app.route('/')
    def index():
        width, height = detector.camera.resolution
        display_width = 1280
        display_height = int(display_width * (height/width))
        return f"""
        <html>
        <head>
            <title>WRO Obstacle Detection Stream</title>
            <style>
                body {{
                    font-family: sans-serif;
                    text-align: center;
                    background-color: #282c34;
                    color: white;
                }}
                img {{
                    border: 2px solid #61dafb;
                    margin-top: 20px;
                }}
            </style>
        </head>
        <body>
            <h2>WRO Obstacle Detection (DEBUG MODE)</h2>
            <img src="/video_feed" width="{display_width}" height="{display_height}">
        </body>
        </html>
        """

    return app


# =================================================================
# Main Execution
# =================================================================
if __name__ == '__main__':
    import argparse

    parser = argparse.ArgumentParser(description='Obstacle Detection System')
    parser.add_argument('--mode', type=str, choices=['headless', 'camera_only', 'full'], default='headless',
                        help='Operation mode: headless, camera_only, or full')
    parser.add_argument('--serial', type=str, default='/dev/ttyUSB0',
                        help='Specify serial port (default: /dev/ttyUSB0)')
    args = parser.parse_args()


    # Create detector with serial port override
    mode_enum = OperationMode(args.mode)
    detector = ObstacleDetector(mode=mode_enum, serial_port=args.serial)

    if mode_enum == OperationMode.CAMERA_ONLY:
        print("Starting web server (CAMERA_ONLY mode)...")
        app = create_flask_app(detector)
        app.run(host='0.0.0.0', port=8080, threaded=True)
    elif mode_enum == OperationMode.FULL:
        print("Starting in FULL mode (video + Arduino)...")
        app = create_flask_app(detector)

        import threading
        def processing_loop():
            detector.run_processing_loop()
        t = threading.Thread(target=processing_loop)
        t.daemon = True
        t.start()

        app.run(host='0.0.0.0', port=8080, threaded=True)
    else:
        print("Running in HEADLESS mode: Arduino communication only (no video)")
        detector.run_processing_loop()

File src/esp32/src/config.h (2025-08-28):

#ifndef CONFIG_H
#define CONFIG_H

// =============================================================================
// PIN DEFINITIONS
// =============================================================================

// -- Motor Controller Pins --
const int MOTOR_SPEED_PIN = 5;  // PWM Speed Control
const int MOTOR_DIR1_PIN = 19; // Direction 1
const int MOTOR_DIR2_PIN = 18; // Direction 2


// -- Servo/Steering Pin --
const int SERVO_PIN = 32;

// -- Ultrasonic Sensor Pins --
const int ULTRASONIC_PIN_FRONT = 25;
const int ULTRASONIC_PIN_RIGHT = 26;
const int ULTRASONIC_PIN_LEFT = 27;

// -- Control Button Pin --
const int BUTTON_PIN = 15;

// =============================================================================
// TUNING PARAMETERS & CONSTANTS
// =============================================================================

// -- Motor Control --
const int MOTOR_PWM_CHANNEL = 1;
const int MOTOR_PWM_FREQ = 30000;
const int MOTOR_PWM_RESOLUTION = 8;
const int FORWARD_SPEED = 190; // Speed value from 0-255
const int BACKWARD_SPEED = -195;

// -- Steering Control --
const int SERVO_CENTER_ANGLE = 90; // The exact angle that makes your servo point straight.
const int SERVO_MIN_PULSE = 0;   // Servo pulse width for 0 degrees
const int SERVO_MAX_PULSE = 2000;  // Servo pulse width for 180 degrees
const float STEERING_KP = 3.5;     // Proportional gain for steering correction. Tune this!

// -- Sensor Settings --
const int ULTRASONIC_MAX_DISTANCE_CM = 200; // Max distance for ultrasonic sensors.

// -- Navigation Logic --
const float TURN_TRIGGER_DISTANCE_CM = 55.0; // How close to a wall before deciding to turn.
const float TURN_CLEARANCE_DISTANCE_CM = 100.0; // How much space must be clear to the side to make a turn.
const unsigned long TURN_COOLDOWN_MS = 1000;  // Minimum time between turns.
const int _all_turn = 45;

const int SHT_LOX = 16;

const int NEOPIXEL_PIN = 17;

#endif // CONFIG_H

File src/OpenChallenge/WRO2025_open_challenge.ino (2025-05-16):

#include <Wire.h>
#include <Servo.h>
#include <NewPing.h>

#define TrigPin 7
#define MAX_DISTANCE 200 // Maximum distance we want to ping for (in centimeters). Maximum sensor distance is rated at 400-500cm.
#define SpeedPin 11
#define dir1 12
#define dir2 13


Servo myservo; 
Adafruit_BNO055 bno = Adafruit_BNO055(55, 0x28, &Wire);
sensors_event_t event;
NewPing sonar_left_back(TrigPin, 2, MAX_DISTANCE); 
NewPing sonar_left_front(TrigPin, 3, MAX_DISTANCE); 
NewPing sonar_front(TrigPin, 4, MAX_DISTANCE); 
NewPing sonar_Right_front(TrigPin, 5, MAX_DISTANCE); 
NewPing sonar_Right_back(TrigPin, 6, MAX_DISTANCE); 


float distance =0;
float error = 0 ;
float offsetGyro=0;
float TargetOffset = 0;
float servo_angle = 0;
float angle = 0;
float kp=2.9;
float previousAngle=0;
int offsetGyroNow;
int turn=0;
int centerServo=87;
unsigned long previousMillis = -1750;  


const long interval = 1000;  




void go_Right()
{
    if (sonar_front.ping_cm()<30 &&sonar_front.ping_cm ()> 1 )
    {
        offsetGyro+=90;
        moveStraight();
        turn++;}
    
}

void turn_Right()
{
    unsigned long currentMillis = millis();
  if (currentMillis - previousMillis >= 2000 && turn <= 11) {
    if(error<abs(15)){
    if(sonar_front.ping_cm()<=60 && sonar_front.ping_cm()>1){
      if(sonar_Right_front.ping_cm()>=120 || sonar_Right_front ==0){
      previousMillis=currentMillis;
      Serial.println(error);
      turn++;
     offsetGyro+=90;
    }
    }
    }
    }
}
void turn_left()
{
  unsigned long currentMillis = millis();
  if (currentMillis - previousMillis >= 2000 && turn <= 11) {
    if(error<abs(15)){
    if(sonar_front.ping_cm()<=60 && sonar_front.ping_cm()>1){
      if(sonar_left_front.ping_cm()>=120 || sonar_left_front.ping_cm()==0){
      previousMillis=currentMillis;
      turn++;
     offsetGyro-=90;
    }
    }
    }
    }
}
void turn()
{
  turn_left();
  turn_Right();
}

void moveStraight()
{
  if(offsetGyro==360)
  {
    offsetGyro=0;
  }
   offsetGyroNow=event.orientation.x-offsetGyro;
   if(offsetGyroNow>180)
   {
    offsetGyroNow-=360;
   }
  error=offsetGyroNow-TargetOffset;
  angle=error*kp;
  servo_angle=map(angle,-90,90,centerServo-45,centerServo+45);
  myservo.write(servo_angle);
  motor_Foward();
  turn();

}

void motor_Foward()
{
  digitalWrite(dir1, 1);
  digitalWrite(dir2, 0);
  analogWrite(SpeedPin, 150);

}

void motor_Back()
{
  digitalWrite(dir1, 0);
  digitalWrite(dir2, 1);
  analogWrite(SpeedPin, 150);

}

void Stop()
{
   digitalWrite(dir1, 0);
  digitalWrite(dir2, 0);
  analogWrite(SpeedPin, 0);
  while(true);
}

void setup() {
   Serial.begin(9600);
   pinMode(dir1,OUTPUT);
  pinMode(dir2,OUTPUT);
  pinMode(SpeedPin,OUTPUT);
  myservo.attach(9); 
   myservo.write(centerServo);


   if(!bno.begin())
  {
    /* There was a problem detecting the BNO055 ... check your connections */
    Serial.print("Ooops, no BNO055 detected ... Check your wiring or I2C ADDR!");
    while(1);
  }
 

  offsetGyro=event.orientation.x;

  bno.setExtCrystalUse(true);
 

}

void loop() {
  bno.getEvent(&event);
  moveStraight();

  if(turn>=12 )
  {
    if (millis() - previousMillis >= 1000) {
      Stop();
    }
    
  }
  // Serial.println(event.orientation.x);
  
  
  // Serial.println();

  // Serial.println(error);
  // Serial.println();

  // Serial.println(offsetGyroNow);


  
  // if(turn >= 12)
  // {
  //   delay(300);
  //   digitalWrite(dir1, 0);
  //   digitalWrite(dir2, 0);
  //   analogWrite(SpeedPin, 0);
  //   while(1);
 
  // }
}

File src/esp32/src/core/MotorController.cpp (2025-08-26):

#include "MotorController.h"
#include "../config.h"

MotorController::MotorController(int dir1_pin, int dir2_pin, int speed_pin, Encoder* encoder) {
    _dir1_pin = dir1_pin;
    _dir2_pin = dir2_pin;
    _speed_pin = speed_pin;
    _encoder = encoder;
}

void MotorController::setup() {
    Serial.println("Setting up Motors....");
    pinMode(_dir1_pin, OUTPUT);
    pinMode(_dir2_pin, OUTPUT);
    pinMode(_speed_pin, OUTPUT);
    stop();
}

void MotorController::forward(int speed) {
    digitalWrite(_dir1_pin, HIGH);
    digitalWrite(_dir2_pin, LOW);
    analogWrite(_speed_pin, speed);
}

void MotorController::backward(int speed) {
    digitalWrite(_dir1_pin, LOW);
    digitalWrite(_dir2_pin, HIGH);
    analogWrite(_speed_pin, speed);
}

void MotorController::move(int speed) {
    if (speed > 0) forward(speed);
    else backward(-speed);
}

void MotorController::stop() {
    digitalWrite(_dir1_pin, LOW);
    digitalWrite(_dir2_pin, LOW);
    analogWrite(_speed_pin, 0);
}

void MotorController::stopBreak(int direction) {
    if (direction > 0) {
        move(255);
        delay(100);
    } else if (direction < 0) {
        move(-255);
        delay(100);
    }
    digitalWrite(_dir1_pin, LOW);
    digitalWrite(_dir2_pin, LOW);
    analogWrite(_speed_pin, 0);
}

void MotorController::setTargetSpeed(float targetCmPerSec) {
    _targetSpeed = targetCmPerSec;
}

void MotorController::updatePID() {
    unsigned long now = millis();
    float dt = (now - _lastPIDTime) / 1000.0f; // seconds

    if (dt <= 0.0f || dt > 0.5f) {  // skip if too soon or too long gap
        _lastPIDTime = now;
        _prevDistance = _encoder->getDistanceCm();
        return;
    }

    _encoder->update(); // refresh encoder data

    // Calculate actual speed
    float currentDistance = _encoder->getDistanceCm();
    float actualSpeed = (currentDistance - _prevDistance) / dt; // cm/sec
    _prevDistance = currentDistance;

    // PID calculations
    float error = _targetSpeed - actualSpeed;
    _integral += error * dt;
    float derivative = (error - _prevError) / dt;

    float output = _kp * error + _ki * _integral + _kd * derivative;

    // Update PWM (and clamp)
    _currentPWM += output;

// Clamp to allowed range if moving
if (_targetSpeed != 0) {
    if (_currentPWM > 0) {
        if (_currentPWM < 170) _currentPWM = 170;
        if (_currentPWM > 255) _currentPWM = 255;
    } else if (_currentPWM < 0) {
        if (_currentPWM > -170) _currentPWM = -170;
        if (_currentPWM < -255) _currentPWM = -255;
    }
} else {
    // Stop if target speed is zero
    _currentPWM = 0;
}

move(_currentPWM);

    _prevError = error;
    _lastPIDTime = now;
}

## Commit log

2025-06-21 optimaization code and add new classes button and PID controller and Timer
2025-06-24 fix PID controller and add filters median and karnel to ultrasonic
    [Car.cpp, Tests.h, main.cpp]
2025-06-27 add cameara basic code to avoid obsticales
    [Button.cpp, Car.cpp, Encoder.cpp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]
2025-07-01 add obstacles_challenge and camera code
2025-07-01 Stop tracking calibration_images folder
2025-07-03 add button class
2025-07-03 edit camera code lano jaya al safir
2025-07-03 calculate the angle and the tendon
2025-07-07 add avoid obstale to one box
    [ObstacleAvoider.cpp, SerialCommunicator.cpp, Tests.h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]
2025-07-10 code needs fix in the _com to accept any command
    [ObstacleAvoider.cpp, SerialCommunicator.cpp]
2025-07-15 add TOF distance sensore class
2025-07-20 better avoiding and steering
    [ObstacleAvoider.cpp, SerialCommunicator.cpp, Steering.cpp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]
2025-07-22 test for turn with encoder
2025-07-22 not working rest car
    [ObstacleAvoider.cpp, Tests.h]
2025-08-02 edit working roi and reset car
    [ObstacleAvoider.cpp]
2025-08-07 add garageout fun and edit motor stop
2025-08-11 message corrected for button setup
    [Button.cpp]
2025-08-11 trying to solve the steering problem
    [Tests.h]
2025-08-11 fix steering
2025-08-11 forward is not working anymore after the out parking of tariq and tayseer
    [Tests.h, main.cpp]
2025-08-14 MotorPID not working
2025-08-15 mouaaz try to improve calibration
2025-08-15 create PID motor function
2025-08-17 add 3D designers to documintation
    [Vertical_Type_FPCFFC_connector[1].STL, back wheel rime2 .STL, base gear.STL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]
2025-08-17 refactor the calibration
2025-08-19 obstacle avoiding working good
    [ObstacleAvoider.cpp, Tests.h, config.h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]
2025-08-19 Revert "Merge branch 'main' of https://github.com/Tariq-Sabbagh/WRO_Future_Engineers_2025"
    This reverts commit 561d4316d15b53ba17424307f00177cc08120063, reversing
    changes made to 34caf5828edb51188c8a250949bc4bb5bdc3cc94.
    [Vertical_Type_FPCFFC_connector[1].STL, back wheel rime2 .STL, base gear.STL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]
2025-08-21 out parcking reset and car edit open challenge
    [Car.cpp, ObstacleAvoider.cpp, Tests.h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]
2025-08-22 final doc and update the global read me
    [Vertical_Type_FPCFFC_connector[1].STL, back wheel rime2 .STL, base gear.STL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]
2025-08-25 rewrite garage with function with not working yet
    [ObstacleAvoider.cpp, config.h]
2025-08-26 Open Challenge working and reset car with button
    [Button.cpp, ObstacleAvoider.cpp, OpenChallenge.cpp]
2025-08-27 test and calibrate no worcking
2025-08-28 color calibration wro syria
